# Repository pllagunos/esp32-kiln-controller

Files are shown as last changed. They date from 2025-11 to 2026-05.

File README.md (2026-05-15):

# ESP32 Electric Kiln Controller

Open-source, DIY controller for electric kilns. Built with an ESP32 microcontroller as brains to provide PID temperature control, a TFT display as an HMI, a web interface for creating and managing firing schedules and real-time data logging capability with InfluxDB and visualization in Grafana.

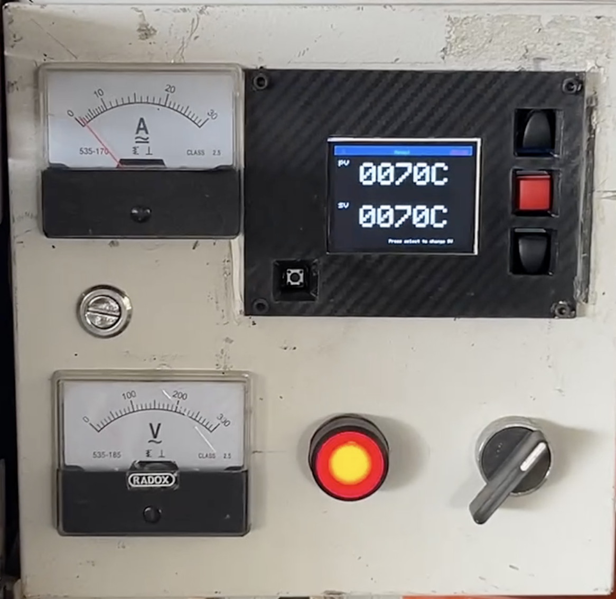
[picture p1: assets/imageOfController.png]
Kiln Controller Demo
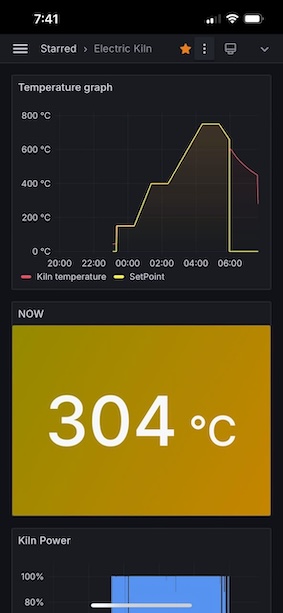
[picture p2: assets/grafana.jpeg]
Grafana
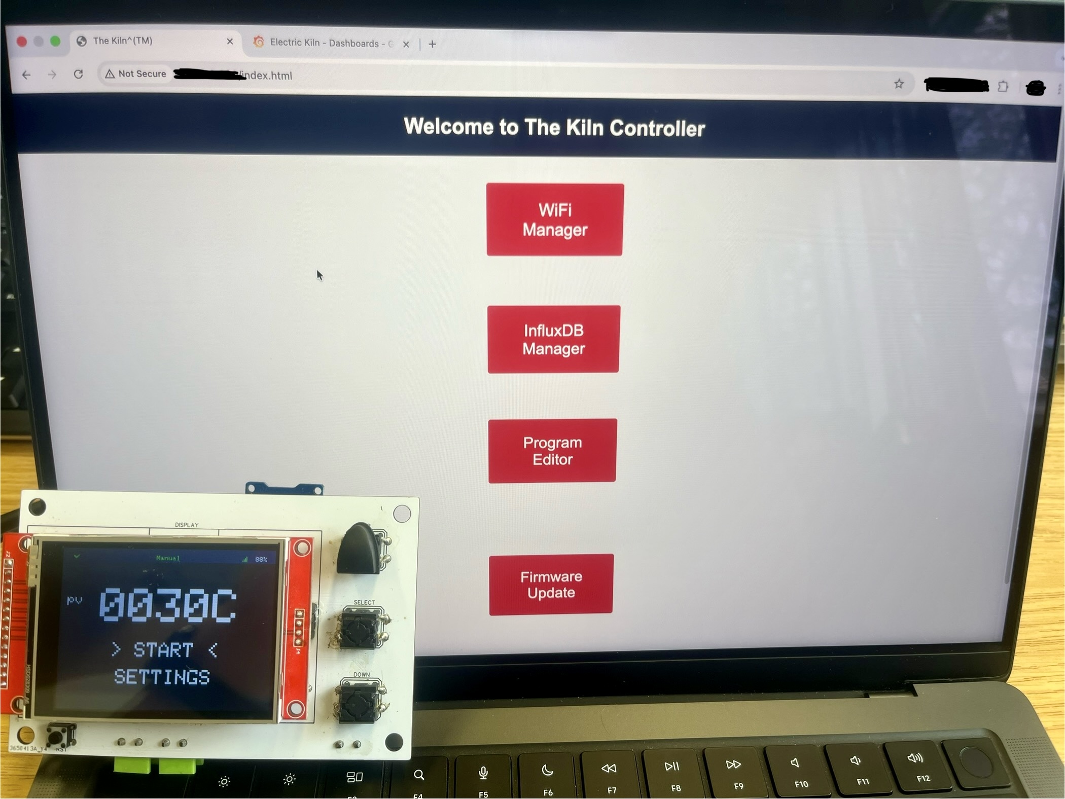
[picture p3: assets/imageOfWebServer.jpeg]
Configuration web server
|  |  |  |
|:---:|:---:|:---:|
| **Control Panel** <br> *(During manual operation with fixed SP)*  | **Grafana** <br> *(Real-time visualization of kiln)* | **Configuration Portal** <br> *(Web server for main settings)* |

## Features

* **PID Temperature Control:** Accurate and stable temperature regulation for your kiln.
* **Multi-segment Firing Programs:** Create complex firing schedules with up to 20 segments, each with a target temperature, firing rate, and hold time.
* **Captive Portal Web Interface:** Configure WiFi, InfluxDB credentials, and firing programs through a web interface hosted directly on the ESP32 — no app required. Accessible at `http://192.168.4.1` when in AP mode.
* **InfluxDB Configuration via Web UI:** Enter and update your InfluxDB credentials (URL, API token, org, bucket, timezone) through the web interface. Credentials are saved to SPIFFS and survive reboots — no recompile needed.
* **Real-time Data Logging:** Pushes temperature data to InfluxDB for live monitoring and analysis in Grafana.
* **Safety Features:** Includes a door-mounted limit switch to shut down the kiln if the door is opened.
* **Simulation Mode:** Test firing programs without actually heating the kiln.
* **OTA Firmware Updates (untested):** Check for and install firmware updates directly from the web interface. Updates are pulled from GitHub Releases automatically when a new release is published.

## Hardware

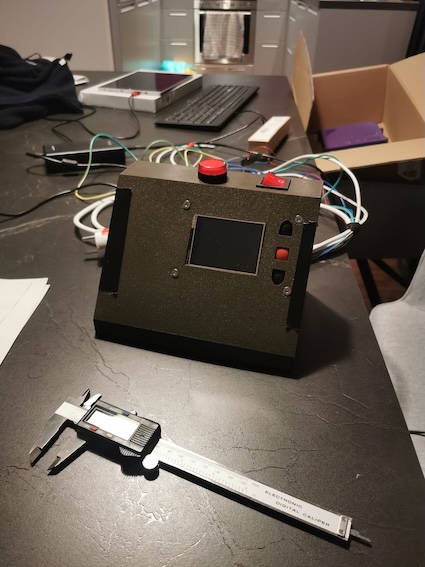
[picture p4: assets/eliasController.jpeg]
Elias controller
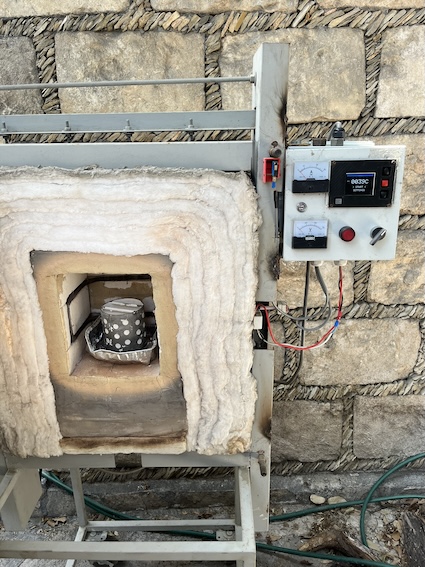
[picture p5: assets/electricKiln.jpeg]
fullKiln
|  | |
|:---:|:---:|

See the Hardware [README](hardware/README.md) for details on how to setup the electrical connections and PCBs.

## Software and Installation

This project is built using [PlatformIO](https://platformio.org/).

### Prerequisites

* [Visual Studio Code](https://code.visualstudio.com/)
* [PlatformIO IDE Extension](https://platformio.org/platformio-ide)

### Dependencies

The following libraries are used in this project and will be installed automatically by PlatformIO:

* `bodmer/TFT_eSPI @^2.5.43`
* `wollewald/ADS1220_WE @ 1.0.15`
* `br3ttb/PID @ 1.2.1`
* `tobiasschuerg/ESP8266 Influxdb @ 3.13.1`
* `me-no-dev/AsyncTCP @ 1.1.1`
* `me-no-dev/ESPAsyncWebServer @ 1.2.4`
* `bblanchon/ArduinoJson @ 6.21.4`

### Simulation mode 

The controller has the capability to use First Order Plus Dead Time (FOPDT) model, see [sensor_task](lib/task/sensor_task.cpp) :: void readSimulatedTemp() for implemenation details.

At the moment one activates/deactivates via the following line in the [user setup](/src/userSetup.h):

```cpp
const bool SIMULATION = false;   
```
(future feature: toggle simulation mode via TFT screen or web config portal)

### Installation Steps

1. **Clone the repository:**
   ```bash
   git clone https://github.com/pllagunos/ElectricKiln.git
   cd ElectricKiln
   ```

2. **Upload the filesystem:**
   * The web interface files are stored in the `/data` directory.
   * In PlatformIO, run the **"Upload Filesystem Image"** task. This uploads the HTML, CSS, and JavaScript files to the ESP32's SPIFFS partition.
   > **This step is required before first use.** The device cannot serve the web UI without it.

3. **Build and Upload:**
   * Connect your ESP32 to your computer.
   * In PlatformIO, click the **"Upload"** button (or run `pio run --target upload`).

## Configuration and Usage

The TFT display acts as the user interface together with the three push buttons next to it (Up, Select and Down).

The screen always shows a topbar with:
- Left corner: InfluxDB status: green checkmark = OK, red cross = FAIL.
- Center: Operating mode: Manual, Automatic.
- Right: Network status: OFFLINE, Connecting..., Signal Strength.

The main screen shows present temperature (PV), START and SETTINGS. The `> <` arrows shows which option is selected, to enter it one must click select.

**START SCREEN** shows preview of the program to load (or goes directly to running screen if in manual mode):

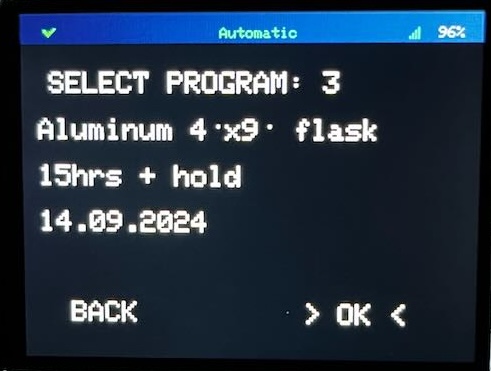
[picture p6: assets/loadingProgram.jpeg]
programsLoading


**RUN SCREEN** shows PV and SP

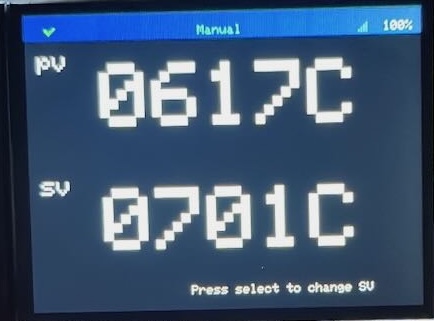
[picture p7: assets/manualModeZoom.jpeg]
manualRun

   - **Manual mode**: exit by clicking the UP button. Adjust setpoint by clicking select.
   - **Automatic mode**: exit by clicking the UP button while in the PV, SP screen. Navigate to tools screens with DOWN button.

**SETTINGS SCREEN** change firing mode, select program or enter config mode via captive portal.

### First Boot — WiFi Setup

By default the controller starts without AP mode and tries to connect to available networks. If it finds none, the controller will show an OFFLINE status in the top right corner.

To configure the WiFi network or add a new one:

1. Using the TFT display and navigation buttons go to: SETTINGS → CONFIG → START CAPTIVE PORTAL. The controller will start **Access Point (AP) mode**.
2. Connect your phone or computer to the WiFi network named **"The Kiln Controller"**.
3. A captive portal opens automatically. If it doesn't, navigate to `http://192.168.4.1`. 
4. Click **"WiFi Manager"** → scan for and select your home/studio network → enter the password → Submit.
5. When you are done configuring internal settings via the captive portal, click Exit at the bottom or > STOP CAPTIVE PORTAL < at the display.

### Creating Firing Programs

1. Open the captive portal or navigate to the device IP on your local network.
2. Click **"Program Editor"** to create and save firing programs.
3. Each segment defines a **target temperature**, **firing rate (°C/hr)**, and **hold time (min)**.

### InfluxDB Setup (Optional — for data logging)

InfluxDB credentials are configured entirely at runtime through the web UI — no recompile needed.

1. Open the captive portal (AP mode) or navigate to the device's IP address on your local network.
2. Click **"InfluxDB Manager"**.
3. Fill in:
   * **URL** — your InfluxDB instance, e.g. `https://us-east-1-1.aws.cloud2.influxdata.com`
   * **Token** — an API token with write access to your bucket
   * **Org** — your InfluxDB organization name or email
   * **Bucket** — the bucket to write data to
   * **Timezone** — POSIX tz string, e.g. `CST+6CDT,M4.1.0/2,M10.5.0/2`
4. Click **Save**. Credentials are stored in SPIFFS and survive reboots.

> **Note:** The API token is never sent back to the browser after saving — only the URL, org, bucket, and timezone are pre-filled when you revisit the form.

To set up InfluxDB Cloud and Grafana for visualization:
1. Sign up at [influxdata.com](https://www.influxdata.com/) and create a bucket.
2. Generate an API token with write access.
3. In Grafana, add InfluxDB as a data source and import the sample dashboard from `/grafana/dashboard.json`.

 **After importing the dashboard**, you'll need to update two things to match your setup:
 - **Datasource**: In each panel's query editor, switch the datasource to your own InfluxDB datasource.
 - **Bucket name**: The queries reference a bucket named `"Station of Analysis"` — update them to match whatever you named yours.
 - **Measurement name**: If you change the default data point name `"HORNO ELECTRICO"` (`/lib/task/database_task.cpp`) make sure to change this in the grafana data selector.

### Over the air (OTA) Firmware Updates

The device can check for and install firmware updates directly from GitHub Releases — no USB cable needed after initial flashing.

**How it works:**
* When a new GitHub Release is published, the CI pipeline automatically builds the firmware and filesystem image, attaches binaries to the release, and appends the firmware's MD5 hash to the release notes.
* The device compares the current `OTA_VERSION` build flag against the release **tag**.
* If a newer version is available, the "Update Now" button appears.
* Firmware integrity is verified with an MD5 hash fetched from the GitHub API before flashing.

**To check for updates:**
1. Make sure the device is connected to WiFi.
2. Navigate to the device's IP address on your local network → **"Firmware Update"** → **"Check for Update"**. 
3. If an update is found, click **"Update Now"**. The device downloads, verifies, flashes, and restarts automatically (~60 seconds).
> **Do not power off the device during an update.**

**To publish a new release (for developers):**
1. Go to the GitHub repo → Releases → "Draft a new release".
2. Create a tag (e.g. `v1.0.1`). The controller compares against the tag.
3. Click "Publish release". GitHub Actions will build and attach the firmware binary, and append the MD5 hash to the release notes automatically.

## Contributing

Contributions are welcome! Feel free to open an issue or submit a pull request.

## To Do
- [ ] MAX31855 capability (max31856 shortage)
- [ ] Autotune PID (look for existing pid autotune projects)

## License

This repository uses a dual-license model:

- Firmware and software source code are licensed under the **MIT License**. See [`LICENSE`](LICENSE).
- Hardware design files in [`hardware/`](hardware/) are licensed under the **CERN Open Hardware Licence Version 2 - Weakly Reciprocal**. See [`LICENSE-HARDWARE`](LICENSE-HARDWARE).

Unless otherwise noted, documentation and images in this repository are provided under the same license as the part of the project they accompany.

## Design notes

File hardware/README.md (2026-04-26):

# Hardware Instructions

The controller is intended for electrical kilns which use resistive heating. Power is controlled via a solid state relay (SSR) energizing the heating coil for a percentage of a heating-cycle. Through the use of a DPDT relay we have a redundant safety power disconnect when the kiln door is opened.

Using the latest PCB and a two phase 220VAC system, a hardware connection of the controller to the kiln looks like this:
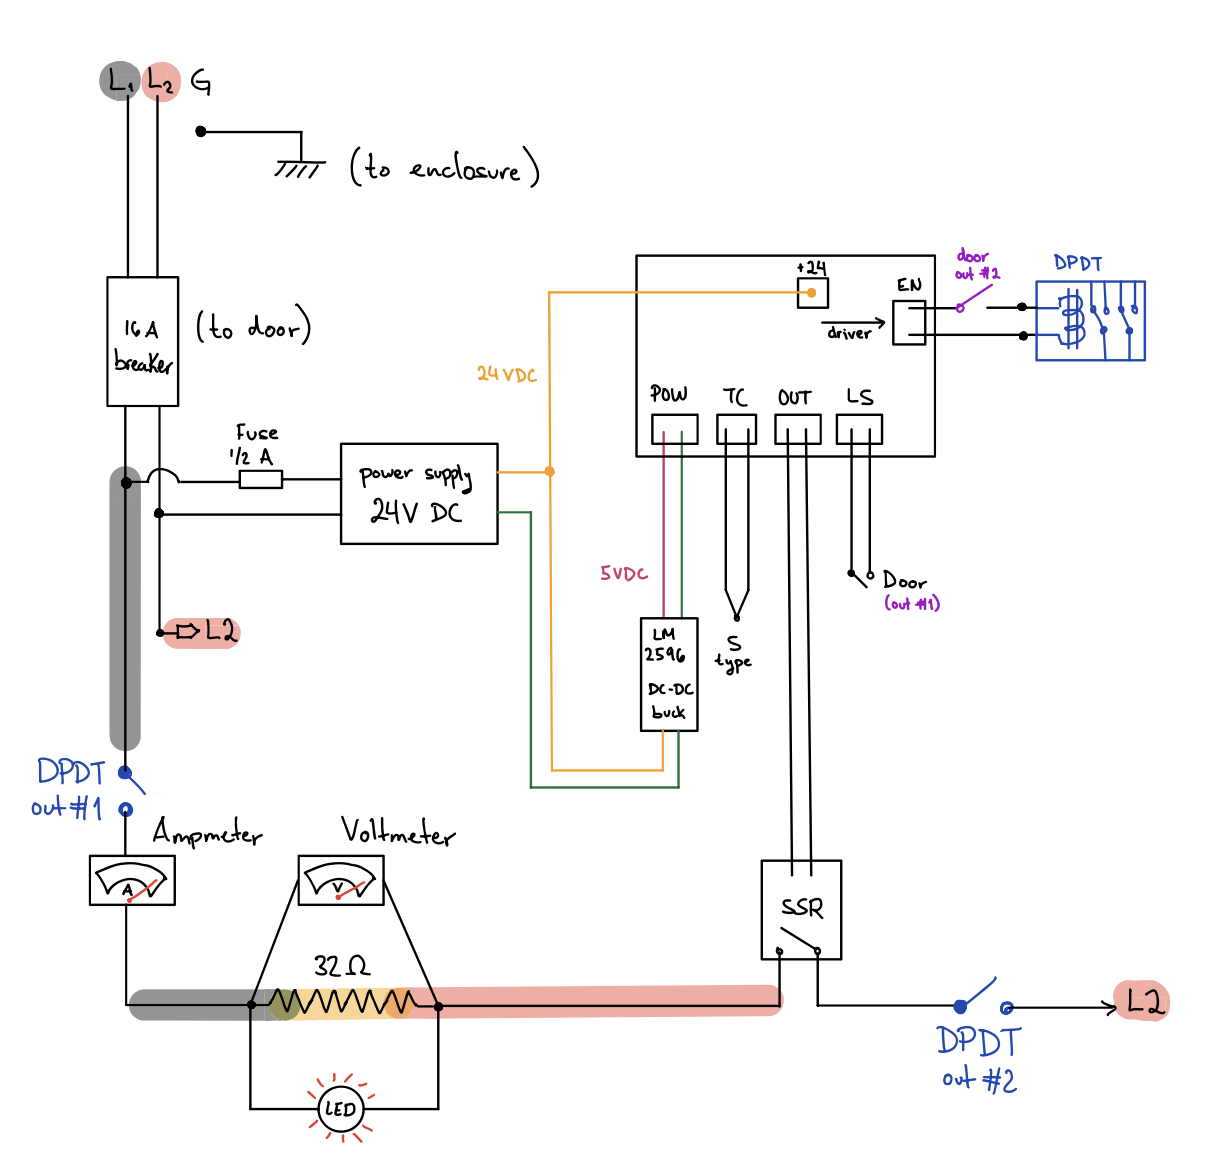
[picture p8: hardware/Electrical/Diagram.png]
Electrical Schematic
 

The electrical schematic can be adapter to one's system easily. However for safety related reasons one should always include: overcurrent protection, relay + SSR, door switch.
> **WARNING**: Wiring high voltage AC systems is a dangerous procedure if one is not familiar with mains power and safe practices. Always work with deenergized, disconnected systems. Use appropriate fuses/breakers and wires following local norms. The user is solely responsible for any damage or injury that may happen from inappropriate implementations.

## License

The hardware design files in this directory are licensed under the **CERN Open Hardware Licence Version 2 - Weakly Reciprocal**. See [`../LICENSE-HARDWARE`](../LICENSE-HARDWARE) for the full license text.

## Hardware Components

### Electronics

* **Microcontroller:** ESP32-DOIT-DEVKIT-V1 board
* **Thermocouple Amplifier:** MAX31856 thermocouple module board or an ADS1220 ADC converter.
* **Thermocouple:** Type-S Thermocouple (but configurable for B, K, R, N, E, J, and T types).
* **Solid State Relay (SSR):** To control the heating elements.
* **Main DPDT Relay:** Double pole double throw, disconnects main power.
* **TFT Display:** ILI9341 320x240 SPI display for the user interface (2.4 or 2.8 inch).
* **Buttons:** Three push buttons for on-device navigation (Up, Select, Down).
* **Limit Switch:** A safety switch for the kiln door.
* **Reset Button:** A reset button for the ESP32.

### PCB and Wiring

The PCB design files can be found in the `/hardware/PCB` directory. 

- `ADS1220 versions` is the current software supported version. The problem with this version is its missing some key details and I haven't done routing / manufacturing. The ESP32 pinout file is at [PINOUT.xlsx](PCB/ADS1220%20versions/PINOUT_HornoElectrico.xlsx).

- `MAX31856 versions` are older PCBs I designed when the project utilized a MAX31856 and an SD card. The ESP32 pinout file is at [PINOUT.xlsx](PCB/MAX31856%20versions/PINOUT_EliasKiln.xlsx). 

Currently I am using the MAX31856 version PCB with modifications that make it reassemble the ADS1220 PCB: 
* The MAX31856 SPI pins were rerouted to a small perfboard where I placed the ADS1220 in place. 
* The SD card module is not needed and I modified it to use the kiln DPDT with a relay driver as follows:

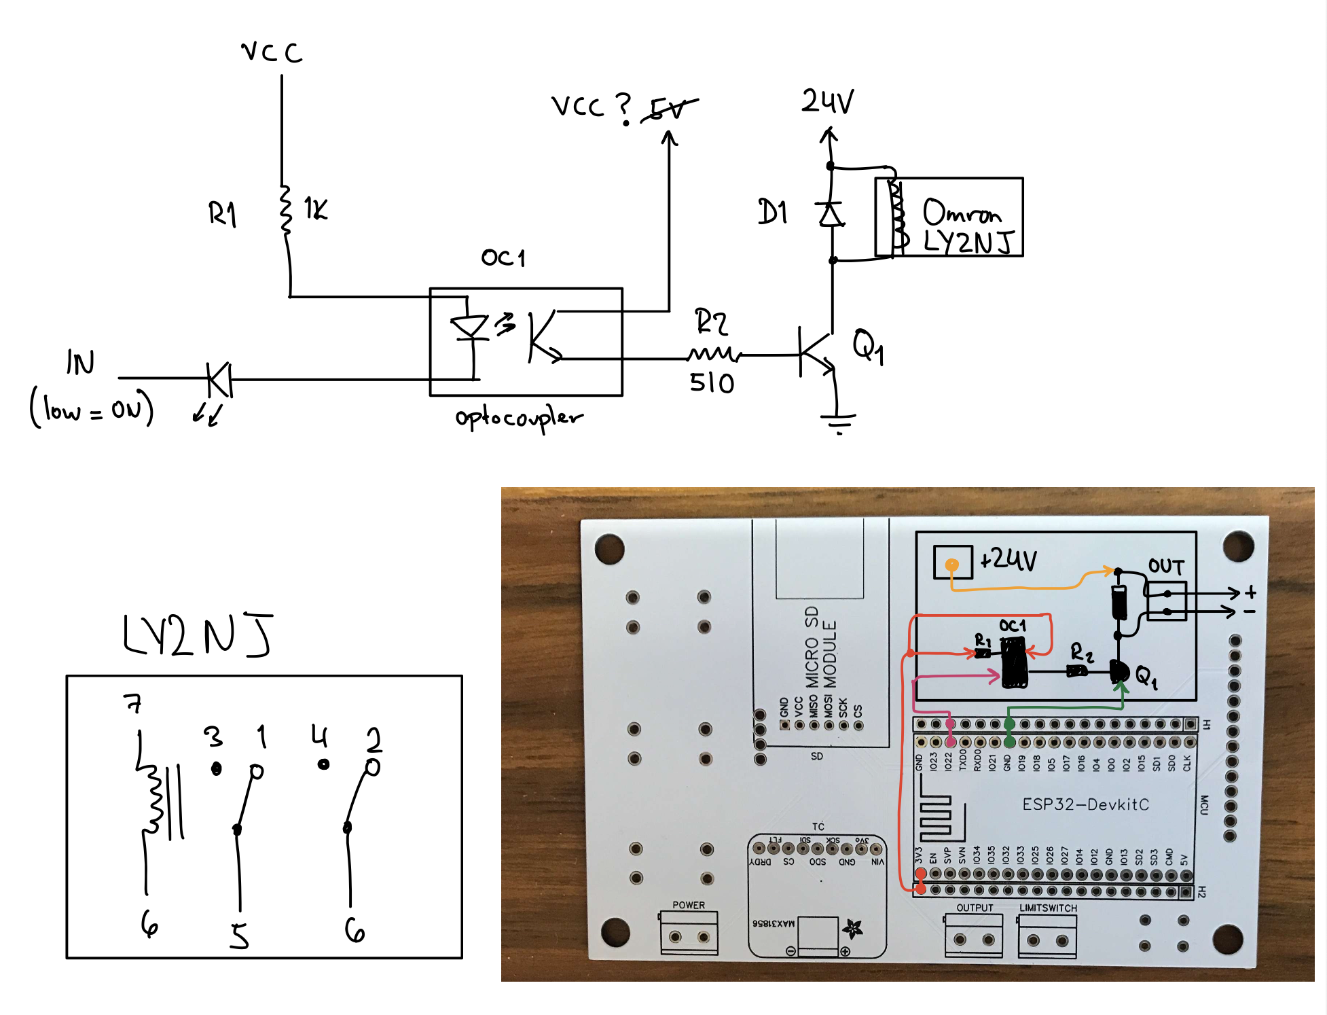
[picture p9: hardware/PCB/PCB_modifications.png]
modifications


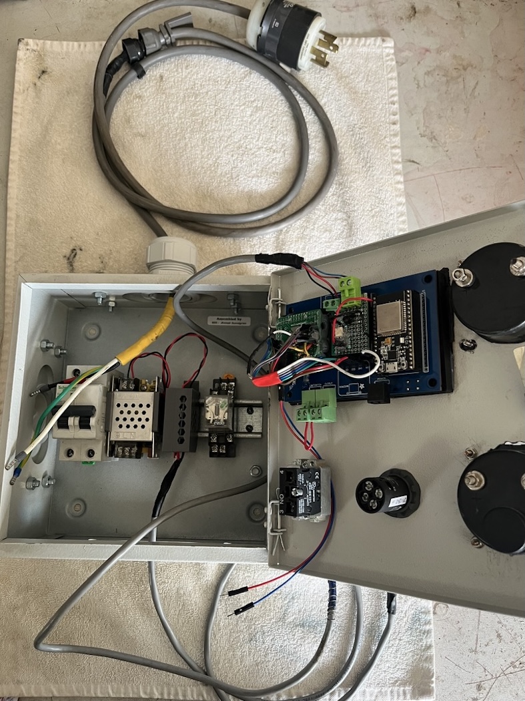
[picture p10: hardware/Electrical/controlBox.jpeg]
controlBox


Since these modifications are custom and would be a lot of work for anybody, there are currently only two approaches to using this project:

1. Finish the ADS1220 PCB design and fabricate it, testing it works as expected.
2. Use the MAX31856 PCB design. Software needs added compatibility of MAX31856 library (easy). Hardware will need a hack to use the safety relay (easy, use any pin to drive relay board directly).

### Optional ADS1220 thermocouple amplifier
The ADS1220 thermocouple software and electronics design are based on the following article: [TI Precision Deisgns: Precision Thermocouple Measurement with the ADS1118](https://www.ti.com/lit/ug/slau509/slau509.pdf?ts=1700893585527&ref_url=https%253A%252F%252Fwww.google.com%252F)

The article is very informative and definetely worth a read to better understand how the Electric Kiln Controller reads temperatures using the ADS1220 ADC. 

For generating the necessary lookup tables I created a [python notebook](./TC%20table%20optimization/ThermocoupleCSV.ipynb) which uses the NIST ITS-90 Thermocouple Database. The generated lookup tables csv files are then uploaded to the `data/` folder which is then uploaded to ESP32's flash. The notebook is quite self explanatory, includes a testing section for validation and can be extended to generate more than the available (K, R, S) thermocouple tables by simply loading the respective NIST table.

### New PCB to-do list:

- [ ] Include 5V stepdown in board
- [ ] Do routing 
- [ ] Create gerber files
- [ ] Potentially use 24V system with chineseium PCB powersupplies

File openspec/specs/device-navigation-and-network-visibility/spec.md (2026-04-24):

## ADDED Requirements

### Requirement: Secondary web UI pages provide explicit navigation controls
The system SHALL provide Back and Home navigation controls on secondary web UI pages so operators can return to the main dashboard or the previous relevant UI flow without relying on browser chrome.

#### Scenario: User navigates from a secondary page to the dashboard
- **WHEN** the user is on a secondary web UI page and activates Home
- **THEN** the UI returns the user to the main dashboard

#### Scenario: User navigates back from a secondary page
- **WHEN** the user is on a secondary web UI page and activates Back
- **THEN** the UI returns the user to the previous relevant page or flow

### Requirement: CONFIG TFT screen shows the active IP address
The system SHALL display the active device IP address on the CONFIG TFT subscreen so operators can discover how to reach the device from the controller itself.

#### Scenario: Device is connected in station mode
- **WHEN** the device has an active station-mode network connection
- **THEN** the CONFIG TFT subscreen displays the current station IP address

#### Scenario: Captive portal is active
- **WHEN** the captive portal is active
- **THEN** the CONFIG TFT subscreen displays the active AP IP address

#### Scenario: No IP address is available
- **WHEN** the device does not have an active IP address for the current mode
- **THEN** the CONFIG TFT subscreen shows that the IP address is unavailable

### Requirement: CONFIG TFT screen allows thermocouple-type selection
The system SHALL provide a `Change TC Type` option on the TFT CONFIG subscreen and SHALL allow the operator to open a dedicated thermocouple-type selection subscreen from that option.

#### Scenario: Operator opens thermocouple-type selection
- **WHEN** the operator highlights `Change TC Type` on the CONFIG TFT subscreen and presses select
- **THEN** the UI opens a dedicated thermocouple-type selection subscreen

### Requirement: Thermocouple-type selection uses the standard TFT button flow
The thermocouple-type selection subscreen SHALL use the existing up/down/select button interaction pattern to browse available thermocouple types and confirm the selected value.

#### Scenario: Operator browses thermocouple types
- **WHEN** the operator is on the thermocouple-type selection subscreen and presses the up or down buttons
- **THEN** the UI cycles through the available thermocouple-type options one step at a time

#### Scenario: Operator confirms the highlighted thermocouple type
- **WHEN** the operator presses select on the thermocouple-type selection subscreen
- **THEN** the highlighted thermocouple type becomes the selected runtime thermocouple type
- **AND** the UI returns to the appropriate parent CONFIG flow or otherwise indicates the selection was accepted

### Requirement: Active thermocouple-type changes are highlighted in orange
The thermocouple-type value displayed while the operator is actively toggling through options SHALL render in orange on the TFT.

#### Scenario: Operator is actively changing the thermocouple type
- **WHEN** the operator is browsing thermocouple-type values before confirmation
- **THEN** the currently highlighted thermocouple-type text is shown in orange

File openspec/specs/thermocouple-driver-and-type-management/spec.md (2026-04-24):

### Requirement: The firmware supports build-time thermocouple driver selection
The system SHALL allow the firmware build to target either the ADS1220 thermocouple path or the MAX31856 thermocouple path from `userSetup.h`, and the configured thermocouple driver SHALL be the only thermocouple hardware path initialized at runtime.

#### Scenario: Firmware is built for ADS1220
- **WHEN** the build is configured to use ADS1220 as the thermocouple driver
- **THEN** the sensor task initializes and reads temperature through the ADS1220 path
- **AND** the MAX31856 hardware path is not initialized

#### Scenario: Firmware is built for MAX31856
- **WHEN** the build is configured to use MAX31856 as the thermocouple driver
- **THEN** the sensor task initializes and reads temperature through the MAX31856 path
- **AND** the ADS1220 hardware path is not initialized

### Requirement: Thermocouple type is runtime-configurable and persisted
The system SHALL maintain a runtime thermocouple-type setting that is initialized from the configured default when no persisted value exists, SHALL persist operator changes, and SHALL reuse the persisted value after restart.

#### Scenario: Device boots without a stored thermocouple type
- **WHEN** the firmware starts and no thermocouple type has been stored previously
- **THEN** the runtime thermocouple type is seeded from the configured default in `userSetup.h`

#### Scenario: Operator changes thermocouple type
- **WHEN** the operator selects and confirms a new thermocouple type from the TFT flow
- **THEN** the system stores the selected thermocouple type for future boots
- **AND** the new thermocouple type becomes the runtime thermocouple type

#### Scenario: Device restarts after a thermocouple type change
- **WHEN** the firmware starts after a thermocouple type has been stored
- **THEN** the runtime thermocouple type uses the stored value instead of reverting to the compile-time default

### Requirement: The active driver applies runtime thermocouple-type changes
The system SHALL apply the current runtime thermocouple type through the configured driver both during initialization and after a confirmed runtime change.

#### Scenario: MAX31856 applies the selected type
- **WHEN** MAX31856 is the configured driver and the runtime thermocouple type is available
- **THEN** the system configures MAX31856 to use the selected thermocouple type before or during temperature acquisition

#### Scenario: ADS1220 applies the selected type
- **WHEN** ADS1220 is the configured driver and the runtime thermocouple type is available
- **THEN** the system loads and uses the lookup-table data required for the selected thermocouple type before temperature acquisition continues

#### Scenario: Runtime type changes after boot
- **WHEN** the operator confirms a different thermocouple type while the device is running
- **THEN** the sensor task reapplies the thermocouple-type configuration for the active driver
- **AND** subsequent temperature reads use the newly selected type

### Requirement: Unsupported thermocouple-type or driver errors are surfaced clearly
The system SHALL not silently coerce an unsupported thermocouple type to another type, and SHALL provide clear fault or initialization feedback when the configured driver cannot initialize or cannot apply the selected thermocouple type.

#### Scenario: Driver initialization fails
- **WHEN** the configured thermocouple driver cannot be initialized
- **THEN** the system surfaces a clear thermocouple-related error to the operator

#### Scenario: ADS1220 lacks data for the selected type
- **WHEN** ADS1220 is configured and the selected thermocouple type does not have usable lookup-table data
- **THEN** the system reports that the selected thermocouple type cannot be applied
- **AND** the thermocouple path is not treated as successfully initialized

#### Scenario: Operator selects a type that cannot be applied
- **WHEN** the operator confirms a thermocouple type that the configured driver cannot use
- **THEN** the system preserves the selected thermocouple type value
- **AND** the system exposes a fault or error state instead of silently substituting another type

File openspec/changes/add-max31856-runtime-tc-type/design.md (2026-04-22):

## Context

The current firmware hard-codes a single thermocouple driver path in `sensor_task.cpp`: ADS1220 setup, ADS1220 reads, and ADS1220 lookup-table loading driven by the compile-time `TCTYPE` string in `userSetup.h`. The TFT already has a CONFIG submenu and already persists operator-selected values with `Preferences`, but thermocouple type is not part of that runtime configuration flow.

This change needs to add a second supported driver (MAX31856), preserve the simple compile-time hardware choice in `userSetup.h`, and introduce a runtime thermocouple-type selection flow that works across both supported drivers. The TFT interaction model must stay consistent with the current up/down/select navigation pattern and the existing orange highlight behavior used for actively adjusted values.

Constraints:
- The project is embedded and resource-constrained; the design should extend the existing sensor task and TFT state machine rather than add a large new abstraction layer.
- ADS1220 and MAX31856 support different thermocouple-type application mechanisms: ADS1220 uses SPIFFS CSV lookup tables, while MAX31856 uses hardware enums/register configuration.
- The current system already has known single-user assumptions in the local UI/task model, so the runtime TC-type flow should stay within that model instead of introducing multi-user configuration paths.

## Goals / Non-Goals

**Goals:**
- Allow the firmware to be compiled for either ADS1220 or MAX31856 hardware from `userSetup.h`.
- Provide one runtime thermocouple-type setting that is persisted and applied by whichever configured driver is active.
- Add a TFT CONFIG entry and a dedicated TC-type selection subscreen with up/down/select controls.
- Keep the UI behavior consistent with the existing TFT screens, including orange text while the value is being changed.
- Preserve clear initialization or fault feedback when the selected thermocouple driver or thermocouple type cannot be applied.

**Non-Goals:**
- Adding web-based thermocouple-driver or thermocouple-type configuration.
- Supporting simultaneous dual-driver operation in one firmware image.
- Reworking the full TFT navigation architecture beyond the new CONFIG branch and selection subscreen.
- Solving unrelated display refresh bugs from the reference document unless directly required by the new flow.

## Decisions

### 1. Use compile-time driver selection in `userSetup.h`
The firmware will expose mutually exclusive compile-time driver-selection macros/constants in `userSetup.h` so the build is explicitly targeted to either ADS1220 or MAX31856 hardware.

**Why:** This matches the current project style, keeps the runtime model simple, and avoids dragging unused driver code and hardware initialization into a single dynamically switched image.

**Alternatives considered:**
- **Runtime driver selection:** rejected because the hardware is fixed per device and the added branching, detection logic, and failure modes do not buy much value.
- **Separate forks/files per driver:** rejected because it would duplicate most of the sensor-task flow and drift over time.

### 2. Introduce one shared runtime thermocouple-type state
The runtime-selected thermocouple type will live in shared state (seeded from `userSetup.h` defaults, persisted through `Preferences`, and read by both the GUI and sensor task).

**Why:** The UI needs to display and update the value, while the sensor task needs to apply it to the active driver. Shared state also lets the system reuse the current task-semaphore approach already used for temperatures and faults.

**Alternatives considered:**
- **Leave `TCTYPE` as compile-time-only:** rejected because it does not satisfy runtime reconfiguration.
- **Store the type only inside `Preferences`:** rejected because the sensor task and GUI need a synchronized in-memory value during operation.

### 3. Apply thermocouple-type changes inside the sensor task
The sensor task remains the owner of thermocouple hardware state. It will initialize the active driver at boot, detect runtime TC-type changes, and apply the new type using driver-specific logic:
- MAX31856: map the selected char to `max31856_thermocoupletype_t` and call the hardware setter.
- ADS1220: reload the corresponding lookup table for the selected type and update readiness/fault state if the type is unsupported or the table cannot be loaded.

**Why:** This keeps hardware mutations in one place and avoids letting the UI task manipulate sensor drivers directly.

**Alternatives considered:**
- **Apply type changes directly from the GUI:** rejected because it crosses task boundaries and couples TFT interaction to SPI/SPIFFS operations.
- **Create a new dedicated thermocouple manager task:** rejected as too much complexity for one sensor path.

### 4. Separate “selection in progress” UI state from “applied” driver state
The GUI will track the currently highlighted thermocouple type while the operator is browsing options, and it will only persist/commit when select is pressed. The highlighted text will render in orange while this browsing state is active.

**Why:** This matches the existing manual-temperature-adjustment pattern in `gui.cpp`, where orange indicates an actively changing value.

**Alternatives considered:**
- **Apply on every up/down press:** rejected because it causes repeated hardware churn and noisier error paths while browsing.
- **Use white text only:** rejected because the request explicitly calls for orange while toggling and the project already uses orange for active edits.

### 5. Persist the public TC type independently from driver-specific implementation details
The persisted value will remain a canonical single-character thermocouple-type code (`B`, `E`, `J`, `K`, `N`, `R`, `S`, `T`). Unsupported combinations will be surfaced as initialization/runtime errors instead of silently remapping to another type.

**Why:** The UI and preferences should reflect what the operator selected, not an implementation-specific fallback. This also keeps behavior explicit if ADS1220 only supports a subset of types via lookup tables.

**Alternatives considered:**
- **Silently coerce unsupported values to `K` or the build default:** rejected because it hides operator intent and makes hardware behavior ambiguous.

## Risks / Trade-offs

- **Unsupported TC type for ADS1220 lookup tables** → The UI may allow a selection that the current ADS1220 data files do not support. Mitigation: specify explicit fault/error behavior and mark the driver unready until a supported type is selected.
- **MAX31856 library integration differences** → The Adafruit API and fault semantics may differ from the reference code. Mitigation: keep the spec at behavioral level and call out the mapping/setup work explicitly in tasks.
- **UI-state growth in `gui.cpp`** → Adding another CONFIG subscreen increases the existing string-based screen-state logic. Mitigation: reuse the established `screen == "..."; selection index; readButtons()` pattern instead of inventing a second navigation model.
- **Persistence mismatch on first boot after upgrade** → Existing devices only have compile-time `TCTYPE`. Mitigation: seed preferences from the compile-time default if no runtime value has been stored yet.
- **More initialization/fault paths** → Two drivers plus runtime type changes create more ways to fail. Mitigation: keep the sensor task as the single owner of readiness/error state and specify clear operator-visible error behavior.

## Migration Plan

1. Add compile-time thermocouple-driver selection and runtime TC-type shared state/defaulting.
2. Extend the sensor task with MAX31856 support and driver-specific TC-type application.
3. Add persistence for the runtime TC type so existing devices bootstrap from the compile-time default once and then reuse the stored value.
4. Extend the TFT CONFIG menu with `Change TC Type` and the selection subscreen.
5. Validate both driver builds and confirm the existing ADS1220 path still behaves correctly when runtime TC-type changes are not used.

Rollback is straightforward: rebuild with the previous single-driver ADS1220 path and ignore the runtime preference key. Existing stored TC-type values can be left in preferences because the older firmware does not read them.

## Open Questions

- Whether the project should constrain the TFT selection list to only the types supported by the configured driver, or expose the full thermocouple-type list and surface unsupported selections as runtime errors.
- Whether MAX31856-specific fault details should be surfaced only through the existing generic TFT error flow or also stored for richer diagnostics elsewhere.

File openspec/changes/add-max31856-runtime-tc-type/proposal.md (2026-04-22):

## Why

The controller currently assumes the ADS1220 thermocouple path at build time and a fixed thermocouple type from `userSetup.h`, which blocks MAX31856-based hardware and forces thermocouple-type changes to require a rebuild. This change adds hardware flexibility and lets operators adjust the configured thermocouple type from the device UI when their installed driver supports it.

## What Changes

- Add build-time thermocouple driver selection in `userSetup.h` so the firmware can be compiled for either ADS1220 or MAX31856 hardware.
- Add MAX31856 initialization, read, fault-handling, and thermocouple-type application alongside the existing ADS1220 path.
- Introduce a shared runtime thermocouple-type setting that can be applied after boot and persisted across restarts.
- Extend the TFT CONFIG flow with a `Change TC Type` entry and a dedicated selection subscreen that uses up/down arrows plus select confirmation.
- Render the thermocouple-type value in orange while the user is actively changing it.
- Preserve existing kiln-control behavior when the selected driver or thermocouple type is unavailable, including clear fault or initialization feedback.

## Capabilities

### New Capabilities
- `thermocouple-driver-and-type-management`: Select the thermocouple driver at build time, support MAX31856 hardware, and allow runtime thermocouple-type selection and persistence through the TFT UI.

### Modified Capabilities
- `device-navigation-and-network-visibility`: Expand the CONFIG TFT flow so operators can enter a dedicated thermocouple-type selection screen from CONFIG in addition to the existing IP-visibility behavior.

## Impact

- `src/userSetup.h` thermocouple configuration constants and driver-selection compile-time switches.
- `src/common.h` and shared runtime state for thermocouple type and initialization or fault status.
- `lib/task/sensor_task.cpp` hardware initialization, reading logic, thermocouple-type application, and error handling for both ADS1220 and MAX31856.
- `lib/gui/gui.cpp` CONFIG submenu structure, thermocouple-type selection screen, button handling, and highlight color behavior.
- Preferences or persistent settings storage used by the TFT flow to remember the selected thermocouple type across restarts.

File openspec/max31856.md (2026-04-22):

# REFERENCE CODE

User Setup:
// thermocouple driver

#define TC_DRIVER_MAX31856
// #define TC_DRIVER_ADS1220

constexpr int TC_CS_PIN        = 33; // MAX31856 / ADS1220 chip-select
constexpr int TC_DRDY_PIN      = 13; // ADS1220 data-ready (unused with MAX31856)

ReadSensors TASK:

#include <ADS1220_WE.h>
#include <Adafruit_MAX31856.h>

#ifdef TC_DRIVER_MAX31856
    // Maps the single-char thermocouple type to the Adafruit MAX31856 enum.
    max31856_thermocoupletype_t tcTypeFromChar(char t) {
        switch (t) {
            case 'B': return MAX31856_TCTYPE_B;
            case 'E': return MAX31856_TCTYPE_E;
            case 'J': return MAX31856_TCTYPE_J;
            case 'K': return MAX31856_TCTYPE_K;
            case 'N': return MAX31856_TCTYPE_N;
            case 'R': return MAX31856_TCTYPE_R;
            case 'S': return MAX31856_TCTYPE_S;
            case 'T': return MAX31856_TCTYPE_T;
            default:  return MAX31856_TCTYPE_K;
        }
    }
#endif

void setupADS1220(ADS1220_WE &ads);
void setupThermocouple(Adafruit_MAX31856 &thermocouple);
void readTemps(Adafruit_MAX31856 &thermocouple);
void readTemps(ADS1220_WE &ads);

setup part:

#if defined(TC_DRIVER_MAX31856)
        static Adafruit_MAX31856 thermocouple(TC_CS_PIN);
        if (!startupSim) setupThermocouple(thermocouple);
    #elif defined(TC_DRIVER_ADS1220)
        static ADS1220_WE ads(TC_CS_PIN, TC_DRDY_PIN);
        if (!startupSim) setupADS1220(ads);
    #endif

loop part (for(;;)): (spi mutexes are not needed!)

        // Apply TC type changes to hardware whenever the user updates g_tcType.
        // Guard on !startupSim: if the device booted in simulation mode the hardware
        // drivers were never initialised and must not be called at runtime.
        #if defined(TC_DRIVER_MAX31856)
        if (!currentSim && !startupSim && currentTcType != lastAppliedTcType) {
            xSemaphoreTake(g_spiMutex, portMAX_DELAY); 
            thermocouple.setThermocoupleType(tcTypeFromChar(currentTcType));
            xSemaphoreGive(g_spiMutex);
            lastAppliedTcType = currentTcType;
        }
        #elif defined(TC_DRIVER_ADS1220)
        if (!currentSim && !startupSim && currentTcType != lastAppliedTcType) {
            table.clear();
            // SPIFFS.begin() is idempotent when already mounted; also handles the
            // edge case where a sim-mode boot skipped the initial mount.
            if (SPIFFS.begin()) {
                if (currentTcType == 'R') readCSV("/thermocouple_table_r.csv", table);
                else if (currentTcType == 'K') readCSV("/thermocouple_table_k.csv", table);
                else if (currentTcType == 'S') readCSV("/thermocouple_table_s.csv", table);
                // Mark applied whether or not the table loaded — prevents futile
                // retries for unsupported types or permanently missing CSV files.
                // (SPIFFS failure is still retried via the else-branch below.)
                lastAppliedTcType = currentTcType;
                xSemaphoreTake(g_mutex, portMAX_DELAY);
                g_tcInitialized = !table.empty();
                if (!table.empty()) {
                    g_initErr[0] = '\0';
                } else if (g_initErr[0] == '\0') {
                    // readCSV sets g_initErr on file-not-found; if it didn't
                    // (unsupported type — no branch above), set a generic message.
                    snprintf(g_initErr, sizeof(g_initErr),
                             "TC type %c: no ADS1220 CSV table", currentTcType);
                }
                xSemaphoreGive(g_mutex);
            } else {
                // SPIFFS unavailable: leave lastAppliedTcType unchanged so the
                // same type is retried once SPIFFS recovers.
                xSemaphoreTake(g_mutex, portMAX_DELAY);
                snprintf(g_initErr, sizeof(g_initErr), "SPIFFS mount failed");
                g_tcInitialized = false;
                xSemaphoreGive(g_mutex);
            }
        }
        #endif
        // too much code to be in the loop, migrate to function with some appropriate name like handleTcType()

        // reading part

        (else?)if (!currentSim && tcReady && millis() - tempStart >= (unsigned long)tempCycle) {
            #if defined(TC_DRIVER_MAX31856)
                xSemaphoreTake(g_spiMutex, portMAX_DELAY);
                readTemps(thermocouple);
                xSemaphoreGive(g_spiMutex);
            #elif defined(TC_DRIVER_ADS1220)
                xSemaphoreTake(g_spiMutex, portMAX_DELAY);
                readTemps(ads);
                xSemaphoreGive(g_spiMutex);
            #endif
            tempStart = millis();
        }

        void readTemps(Adafruit_MAX31856 &thermocouple) {

            temp = thermocouple.readThermocoupleTemperature();
            uint8_t faultCode = thermocouple.readFault();

            xSemaphoreTake(g_mutex, portMAX_DELAY);
            g_tcFault     = (faultCode != 0);
            g_tcFaultCode = faultCode;                         // raw bitmask for host diagnostics
            if (temp < 5000.0f && temp > 0.0f) g_temperature = temp;
            xSemaphoreGive(g_mutex);
        }

        // ── Thermocouple driver setup ───────────────────────────────────────────

void setupADS1220(ADS1220_WE &ads) {
    bool ok = false;
    while (!ok) {
        xSemaphoreTake(g_spiMutex, portMAX_DELAY);
        ok = ads.init();
        if (ok) {
            ads.setCompareChannels(ADS1220_MUX_0_1);
            ads.setGain(ADS1220_GAIN_32);
        }
        xSemaphoreGive(g_spiMutex);
        if (!ok) {
            xSemaphoreTake(g_mutex, portMAX_DELAY);
            snprintf(g_initErr, sizeof(g_initErr), "ADS1220 not found");
            xSemaphoreGive(g_mutex);
            delay(200);
        }
    }

    if (!SPIFFS.begin()) {
        xSemaphoreTake(g_mutex, portMAX_DELAY);
        snprintf(g_initErr, sizeof(g_initErr), "SPIFFS mount failed");
        xSemaphoreGive(g_mutex);
    } else {
        xSemaphoreTake(g_mutex, portMAX_DELAY);
        char tcType = g_tcType;
        xSemaphoreGive(g_mutex);

        if (tcType == 'R') readCSV("/thermocouple_table_r.csv", table);
        if (tcType == 'K') readCSV("/thermocouple_table_k.csv", table);
        if (tcType == 'S') readCSV("/thermocouple_table_s.csv", table);
    }

    xSemaphoreTake(g_mutex, portMAX_DELAY);
    g_tcInitialized = !table.empty();
    if (!table.empty()) g_initErr[0] = '\0'; // table loaded — clear prior error
    xSemaphoreGive(g_mutex);
}

void setupThermocouple(Adafruit_MAX31856 &thermocouple) {
    bool ok = false;
    while (!ok) {
        xSemaphoreTake(g_spiMutex, portMAX_DELAY);
        ok = thermocouple.begin();
        xSemaphoreGive(g_spiMutex);
        if (!ok) {
            xSemaphoreTake(g_mutex, portMAX_DELAY);
            snprintf(g_initErr, sizeof(g_initErr), "MAX31856 not found");
            xSemaphoreGive(g_mutex);
            delay(200);
        }
    }

    xSemaphoreTake(g_mutex, portMAX_DELAY);
    char tcType = g_tcType;
    g_initErr[0] = '\0'; // hardware found — clear any prior not-found error
    xSemaphoreGive(g_mutex);

    xSemaphoreTake(g_spiMutex, portMAX_DELAY);
    thermocouple.setThermocoupleType(tcTypeFromChar(tcType));
    thermocouple.setConversionMode(MAX31856_CONTINUOUS);
    xSemaphoreGive(g_spiMutex);

    xSemaphoreTake(g_mutex, portMAX_DELAY);
    g_tcInitialized = true;
    xSemaphoreGive(g_mutex);
}

// MAX31856 error strings (from a different project)
case regAddress::TC_ERROR_CODE :
      tcErrorType = "";
      if (value & MAX31856_FAULT_CJRANGE) tcErrorType += "CJ RANGE\n";
      if (value & MAX31856_FAULT_TCRANGE) tcErrorType += "TCRANGE\n";
      if (value & MAX31856_FAULT_CJHIGH)  tcErrorType += "CJ HIGH\n";
      if (value & MAX31856_FAULT_CJLOW)   tcErrorType += "CJ LOW\n";
      if (value & MAX31856_FAULT_TCHIGH)  tcErrorType += "TC HIGH\n";
      if (value & MAX31856_FAULT_TCLOW)   tcErrorType += "TC LOW\n";
      if (value & MAX31856_FAULT_OVUV)    tcErrorType += "Over/Under Voltage\n";
      if (value & MAX31856_FAULT_OPEN)    tcErrorType += "TC OPEN\n";

      break;

// Call to display error message on TFT display
disp_error_msg("TC ERROR", tcErrorType, "Restart Kiln Controller");

//  DISPLAYERRORMESSAGE: PRINT AN ERROR ON TFT
void disp_error_msg(String title, String message1, String message2) {
  // xSemaphoreTake(disp_mutex, portMAX_DELAY);  // take semaphore
  tft.fillScreen(TFT_BLACK);
  tft.setTextColor(TFT_RED, TFT_BLACK);
  tft.setTextSize(4);
  tftPrintCenterWidth("ERROR", 50);
  tft.setTextColor(TFT_WHITE, TFT_BLACK);
  tft.setTextSize(2);
  tftPrintCenterWidth(title, 100);
  tftPrintCenterWidth(message1, 130);
  tftPrintCenterWidth(message2, 210);
  // xSemaphoreGive(disp_mutex);
}

## Current bug
When no thermocouple driver is detected upon init, the display should show a clear error of this. However the way the TFT is rendering the error, it's flashing very often together with the START screen, making it look defective.

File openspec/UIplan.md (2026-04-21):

**Implementation Plan**

The goal is to upgrade the ESP32 kiln controller’s firing program workflow from a single manual-entry form into a lightweight program library plus editor, while keeping the implementation simple enough for plain HTML, CSS, JS, and filesystem-backed firmware handlers.

1. Discovery and compatibility
   - Locate the current firing program HTML, JS, CSS, and the firmware handler that writes JSON into SPIFFS or LittleFS.
   - Confirm the current program JSON schema, storage directory, filename pattern, and any existing endpoints used by the page.
   - Identify whether existing saved files contain legacy fields such as program_number and whether those files must remain readable.

2. Data model cleanup
   - Standardize new and edited programs to this schema: name, created_date, duration, segments.
   - Standardize each segment to: target_temperature, firing_rate, holding_time.
   - Remove program_number from the UI and from newly saved JSON.
   - Keep legacy compatibility by ignoring program_number if present in old files and removing it when an old file is re-saved.

3. Program storage and naming
   - Replace manual program numbering with automatic filename generation.
   - Generate a slug from program name and created_date.
   - Ensure filenames are filesystem-safe and collision-safe by adding a numeric suffix when necessary.
   - Support editing existing programs so that if name or created_date changes, the backing filename can be updated cleanly.

4. Firmware API additions
   - Add a list endpoint that returns saved program metadata.
   - Add a get endpoint that returns one full program by id or slug.
   - Add a create or update endpoint that saves a program and returns its final id.
   - Optionally add a delete endpoint if straightforward.
   - Make the save handler validate payload shape and compute or verify duration before writing.

5. Frontend structure
   - Split the current single page into two simple views:
   - A program library page listing saved programs with actions for New and Edit.
   - A program editor page for creating and editing programs.
   - Keep the implementation framework-free and lightweight.

6. Editor behavior
   - The editor should expose only name, created date, and segment rows.
   - Each segment row should include target temperature, firing rate, and hold time.
   - Users should be able to add and remove segments dynamically in the browser before saving.
   - The editor should support create mode and edit mode using a query parameter or route segment.

7. Automatic calculations
   - Recalculate ramp time and total duration whenever a segment changes.
   - Use this logic:
   - Ramp minutes = absolute difference between current target and previous target divided by firing rate times 60, only when firing rate is greater than zero.
   - Total duration = sum of all ramp minutes plus all hold minutes.
   - Duration should be displayed as a derived field, not manually entered.

8. Graph preview
   - Add a live preview graph to the editor.
   - Use a small SVG or canvas implementation instead of a heavy charting library.
   - Compute graph points from ramp and hold segments using an ambient start temperature of 20 °C unless the firmware already has a better source for ambient.
   - Redraw on every segment edit.

9. Migration and backward compatibility
   - Ensure old saved programs can still be loaded.
   - When an old program is edited and saved, convert it to the new schema and new filename pattern.
   - Do not break existing kiln start logic that consumes program files.

10. Validation and finish
   - Test create, edit, reload, and save flows.
   - Verify generated filenames are unique and stable.
   - Verify duration and preview update correctly as segments are edited.
   - Verify saved JSON is valid and still usable by the firmware runtime.

**Agent Checklist**

Use this as the execution checklist.

1. Find the current program editor page assets and firmware save handler.
2. Document the current JSON shape and storage path.
3. Remove program_number from the UI.
4. Make program filenames auto-generated from name plus date.
5. Add collision-safe slug generation.
6. Add a program list endpoint.
7. Add a single-program fetch endpoint.
8. Add a create or update save endpoint.
9. Optionally add delete if low effort.
10. Build a lightweight program library page with New and Edit actions.
11. Build or refactor a plain JS editor page that supports create and edit modes.
12. Add dynamic segment add and remove behavior.
13. Compute per-segment ramp timing client-side.
14. Compute total duration client-side and show it read-only.
15. Save duration in the JSON payload automatically.
16. Add a live graph preview using SVG or canvas.
17. Load legacy program files without failing if program_number exists.
18. Strip program_number when saving edited legacy files.
19. Handle rename-on-save when name or created date changes.
20. Verify old and new program files still work with the kiln runtime.

**Acceptance Checklist**

The work is done only if all of these are true.

1. A user can open a list of saved firing programs.
2. A user can create a new program without entering a program number.
3. A user can open an existing program for editing.
4. A user can add and remove segments in the browser.
5. Total duration updates automatically as the program changes.
6. The preview graph updates automatically as the program changes.
7. Saving creates a JSON file with an automatic filename.
8. Editing an existing program updates the correct file, including rename behavior if needed.
9. Legacy files with program_number still load successfully.
10. Re-saved legacy files are converted to the new schema.
11. Saved files remain compatible with the firmware logic that starts firing programs.
12. The page stays lightweight and uses plain HTML, CSS, and JS only.

**Prompt For The External Agent**

Paste this as-is to the external agent:

```text
Implement a firing program library and editor for my standalone ESP32 kiln controller project.

Context:
- This project does not use Svelte or any frontend framework.
- The UI is plain HTML, CSS, and JavaScript served by the ESP32.
- Programs are stored as JSON files in SPIFFS.
- There is already an existing firing program page that manually creates a program and submits it to the firmware for saving.
- I want the new implementation to stay lightweight and simple, suitable for an ESP32-hosted web UI.

Goals:
- Add the ability to view saved programs.
- Add the ability to edit existing programs.
- Add a live preview graph of the firing profile.
- Remove the need for program_number.
- Generate program JSON filenames automatically.
- Calculate duration automatically.

Requirements:
- First inspect the current project and identify:
  - The existing firing program HTML, JS, and CSS files.
  - The firmware handlers or routes that save and load program files.
  - The current JSON schema and storage directory.
  - Whether the project uses SPIFFS or LittleFS.
- Keep legacy compatibility. If old files include program_number, they must still load.
- New and updated program files should use this schema:
  - name
  - created_date
  - duration
  - segments
- Each segment should use:
  - target_temperature
  - firing_rate
  - holding_time
- Remove program_number from the UI and from newly saved JSON.
- Use automatic filename generation based on a filesystem-safe slug from program name plus created_date.
- Avoid filename collisions by adding a numeric suffix when needed.
- If an existing program is edited and its name or created_date changes, handle file renaming safely.

Frontend expectations:
- Use plain HTML, CSS, and JS only.
- Create a lightweight program library page that lists saved programs and allows New and Edit.
- Create or refactor a program editor page that supports create mode and edit mode.
- Allow adding and removing segments dynamically.
- Show a read-only derived duration field.
- Add a live preview graph using lightweight SVG or canvas, not a heavy chart library.
- Recompute duration and graph data whenever segment inputs change.

Calculation rules:
- Use an ambient start temperature of 20 C unless the project already has a better configured ambient value.
- Ramp minutes = abs(target - previous_target) / firing_rate * 60 when firing_rate > 0.
- Total duration = sum of all ramp minutes plus all hold minutes.
- Duration should be saved automatically, not entered manually.

Firmware expectations:
- Add or adapt endpoints or handlers for:
  - listing saved programs
  - fetching one program
  - creating or updating a program
- Delete is optional if easy.
- The save handler should validate input and return the final saved id or slug.

Migration expectations:
- Legacy files with program_number must remain loadable.
- When a legacy program is edited and saved, remove program_number and save it in the new format.
- Do not break the firmware’s existing logic that consumes saved program files for firing.

Deliverables:
- Implement the feature end-to-end in the project.
- Summarize the routes, files, and handlers you changed.
- Explain the final JSON format.
- Note any assumptions you had to make.
- Report whether delete was implemented or intentionally deferred.

Acceptance criteria:
- I can view saved programs.
- I can create a new program without entering a program number.
- I can edit an existing program.
- Duration updates automatically.
- The preview graph updates automatically.
- Saved filenames are generated automatically.
- Legacy program files still load.
- Saved programs remain usable by the kiln controller runtime.

Do not introduce a frontend framework. Keep the solution simple, robust, and resource-conscious.
```

** Additional implementations **
- Have back and home buttons in the web UI
- Add IP address to CONFIG TFT subscreen

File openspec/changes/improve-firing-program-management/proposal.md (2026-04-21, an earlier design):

## Why

The kiln controller currently exposes a single manual-entry firing program page, which makes saved-program reuse, editing, and validation cumbersome. This change upgrades the operator experience with a lightweight program library and editor while preserving compatibility with existing program files and adding small navigation/status improvements that reduce friction on both the web UI and device UI.

## What Changes

- Replace manual program-number entry with a lightweight firing program library and editor flow.
- Add firmware-backed list, fetch, and save behavior for firing programs, with optional delete support if it fits the existing handlers cleanly.
- Standardize saved program data around `name`, `created_date`, `duration`, and `segments`, while keeping legacy files readable and converting them when re-saved.
- Generate filesystem-safe program identifiers automatically from program metadata and handle rename collisions safely.
- Add automatic duration calculation, dynamic segment editing, and a live firing-profile preview in the browser without introducing a frontend framework.
- Add consistent back and home navigation controls in the web UI.
- Show the current IP address on the CONFIG TFT subscreen so operators can discover the device address directly from the controller.

## Capabilities

### New Capabilities
- `firing-program-management`: Browse, create, edit, validate, and save firing programs through a lightweight library/editor workflow with legacy-file compatibility.
- `device-navigation-and-network-visibility`: Provide consistent back/home navigation in the UI and expose the active IP address on the CONFIG TFT subscreen.

### Modified Capabilities

None.

## Impact

- Web UI assets for firing program list/editor screens, shared navigation controls, and lightweight preview rendering.
- Firmware routes or handlers responsible for program storage, JSON validation, filename generation, and legacy-program normalization.
- Program files stored in SPIFFS or LittleFS, including rename-on-save behavior and metadata listing.
- TFT configuration-screen rendering for network visibility.

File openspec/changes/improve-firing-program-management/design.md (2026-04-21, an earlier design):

## Context

The current web UI exposes a single `data/firingProgram.html` form that posts multipart form data to `POST /program-editor`. The firmware handler in `lib/network/network.cpp` writes `/firingProgram_<programNumber>.json` files containing `name`, `duration`, `createdDate`, `segmentQuantity`, and `segments`, while the TFT workflow in `lib/gui/gui.cpp` loads programs back by numeric filename through `openProgram()`. The CONFIG TFT subscreen only exposes captive-portal controls, and the device IP address is only emitted to serial logs.

This change needs to modernize the program-management UX without introducing a frontend framework or breaking the kiln runtime’s ability to select and execute saved programs. It also needs to cover two smaller UX improvements: consistent back/home navigation in the web UI and direct IP visibility on the TFT config screen.

## Goals / Non-Goals

**Goals:**
- Introduce a lightweight program library and editor flow for saved firing programs.
- Replace manual program numbering with automatic, filesystem-safe identifiers.
- Persist canonical program JSON using the new schema while keeping legacy files loadable.
- Keep TFT program selection and runtime loading functional after the storage migration.
- Add derived duration and live profile preview in the editor with minimal client-side code.
- Add back/home navigation to secondary web UI screens and show the current IP address on the CONFIG TFT subscreen.

**Non-Goals:**
- Rewriting the web UI with a framework or heavy charting dependency.
- Changing kiln heat-control behavior, firing algorithms, or segment execution semantics.
- Requiring a one-time manual migration step before deployment.
- Committing to delete support as part of the initial contract if it complicates the existing handlers.

## Decisions

### 1. Split the firing-program experience into a library page and an editor page

The web UI will move from a single form page to two lightweight views: a library that lists saved programs and an editor that supports both create and edit flows. This keeps state management simple in plain HTML/JS and makes room for metadata listing, edit actions, and derived previews without overloading the existing form.

**Alternatives considered:**
- Extend the current single page with conditional modes. Rejected because it would mix list, edit, and save concerns in one static page and make navigation/state harder to reason about.
- Build a richer SPA-style client. Rejected because it adds complexity and weight that are not appropriate for an ESP32-hosted UI.

### 2. Store programs under canonical slug-based identifiers and maintain a program catalog

New and updated programs will be stored under filesystem-safe identifiers derived from program name plus created date, with collision-safe numeric suffixes. A lightweight catalog/manifest will track the saved programs and expose metadata for list/fetch/save operations.

This catalog becomes the stable bridge between the web UI, firmware APIs, and TFT program selection. It avoids forcing operators to manage numeric IDs while keeping a deterministic lookup surface for the rest of the system.

**Alternatives considered:**
- Keep numeric filenames as the canonical format. Rejected because it preserves the UX problem the change is trying to remove.
- Use raw names as filenames. Rejected because names are not filesystem-safe or collision-safe.

### 3. Normalize program data at the firmware boundary

The save path will validate and normalize incoming payloads into a canonical schema:
- `name`
- `created_date`
- `duration`
- `segments`

Each segment will be saved as:
- `target_temperature`
- `firing_rate`
- `holding_time`

The loader will accept legacy shapes such as `createdDate`, `segmentQuantity`, camelCase segment fields, and `program_number`/`programNumber`, then normalize them into the in-memory representation. Re-saved legacy programs will be written back only in the canonical schema.

**Alternatives considered:**
- Keep mixed old/new field names indefinitely. Rejected because it makes the data contract ambiguous and increases maintenance cost.
- Migrate all legacy files eagerly on boot. Rejected because it adds risk and unnecessary write amplification.

### 4. Preserve runtime compatibility by selecting programs through catalog entries rather than filename conventions

The TFT program-selection flow currently stores a numeric preference and loads `/firingProgram_<programNumber>.json` directly. Instead of preserving that filename convention, the TFT flow will resolve the selected entry through the catalog and then load the referenced program file. Existing legacy files remain selectable because the catalog builder will include both legacy and canonical files.

This keeps the runtime compatible with saved programs after migration while allowing the storage format to evolve independently of the old numbering scheme.

**Alternatives considered:**
- Dual-write legacy numeric aliases for every new save. Rejected because alias files can drift and create unclear source-of-truth behavior.
- Remove TFT program selection from scope. Rejected because the proposal explicitly requires saved programs to remain usable by the kiln runtime.

### 5. Derive duration and preview client-side, then verify duration on save

The editor will recompute ramp time, total duration, and SVG/canvas preview points whenever segment inputs change. The firmware save handler will still validate payload shape and recompute or verify the submitted duration before persisting, so malformed or stale client data cannot become the source of truth.

**Alternatives considered:**
- Compute duration only on the server. Rejected because the editor would lose immediate feedback.
- Trust the client’s duration completely. Rejected because it weakens validation and migration safety.

### 6. Surface navigation and network visibility with minimal shared UI helpers

Secondary web pages will expose explicit Back and Home controls using the existing plain HTML/JS/CSS structure. The CONFIG TFT screen will render the active IP address from station mode (`WiFi.localIP()`) or captive portal/AP mode (`WiFi.softAPIP()`), and it will show an unavailable state when no address is active.

**Alternatives considered:**
- Keep navigation implicit through browser history only. Rejected because these pages are often used on mobile devices or captive-portal flows where explicit navigation is clearer.
- Leave IP visibility to serial logs. Rejected because operators need the address directly on the device.

## Risks / Trade-offs

- **Catalog drift between files and metadata** -> Rebuild or refresh catalog entries during save/load operations and prefer deriving catalog contents from actual program files when possible.
- **Rename collisions or interrupted updates** -> Use deterministic slug generation, collision suffixing, and replace-on-success semantics when renaming an existing program.
- **Legacy schema variants causing partial loads** -> Centralize normalization so both web and TFT paths share the same compatibility rules.
- **Preview logic adding browser overhead** -> Keep the graph implementation to simple SVG/canvas primitives and update only on editor input changes.

## Migration Plan

1. Add program-catalog and normalization helpers that can enumerate existing program files and read both legacy and canonical schemas.
2. Introduce list/fetch/save firmware handlers backed by the catalog while keeping old program files readable.
3. Update TFT selection/loading to resolve through catalog entries instead of assuming numeric filenames.
4. Replace the current program form with library/editor pages, derived duration, preview rendering, and shared back/home controls.
5. Expose IP information on the CONFIG TFT subscreen.

Rollback relies on two safeguards: legacy files remain untouched until a program is edited and re-saved, and the compatibility loader continues to understand legacy data. If the new UI or catalog flow needs to be reverted, the system still has access to the original program files.

## Open Questions

None blocking. Delete support remains intentionally optional and can be implemented only if it fits the existing handlers without expanding the compatibility surface.

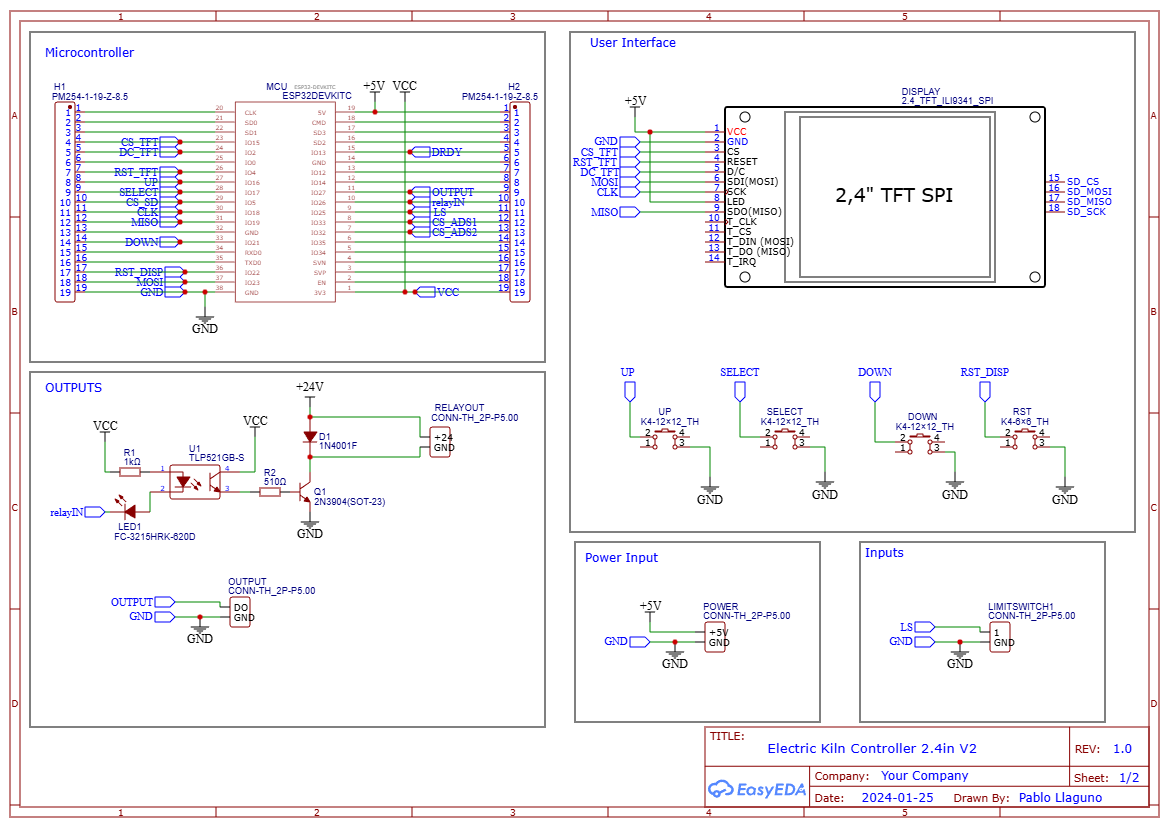
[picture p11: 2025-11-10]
hardware/PCB/ADS1220 versions/2.4in display NEW/Schematic_Electric-Kiln-Controller_Sheet1.png

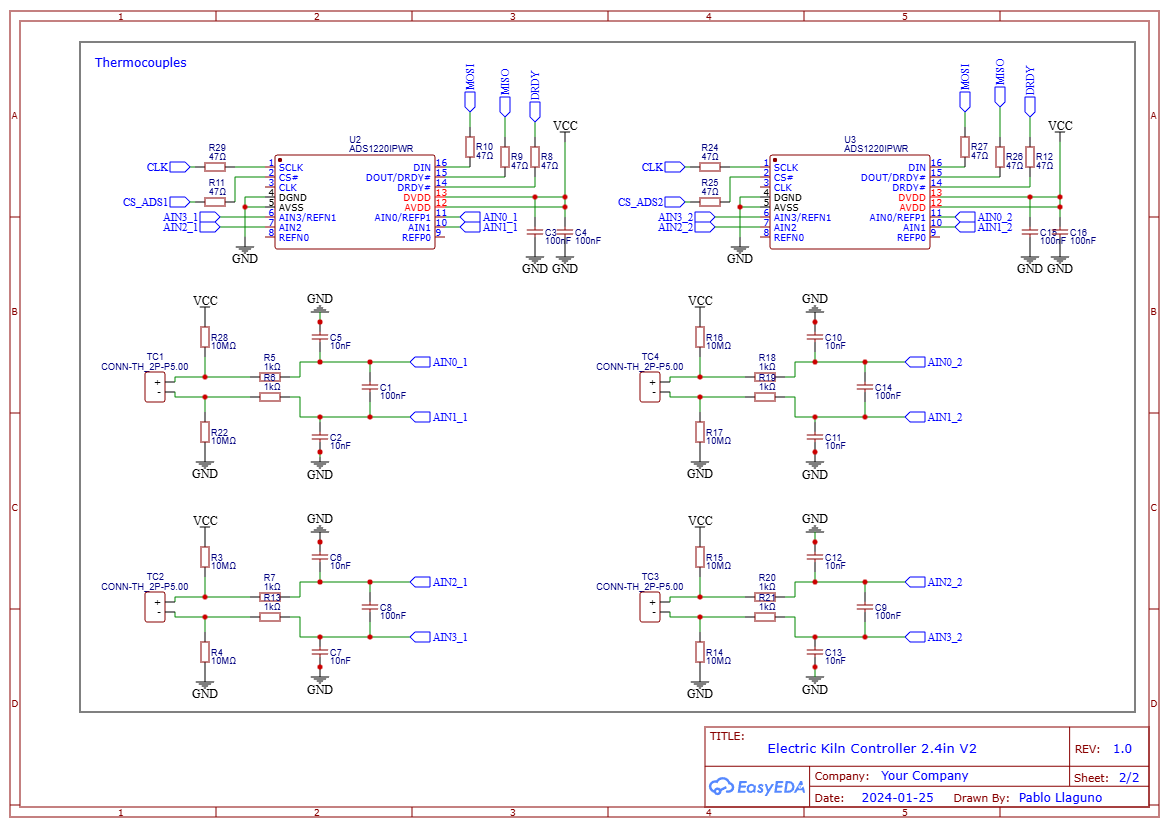
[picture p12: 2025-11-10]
hardware/PCB/ADS1220 versions/2.4in display NEW/Schematic_Electric-Kiln-Controller_Sheet2.png

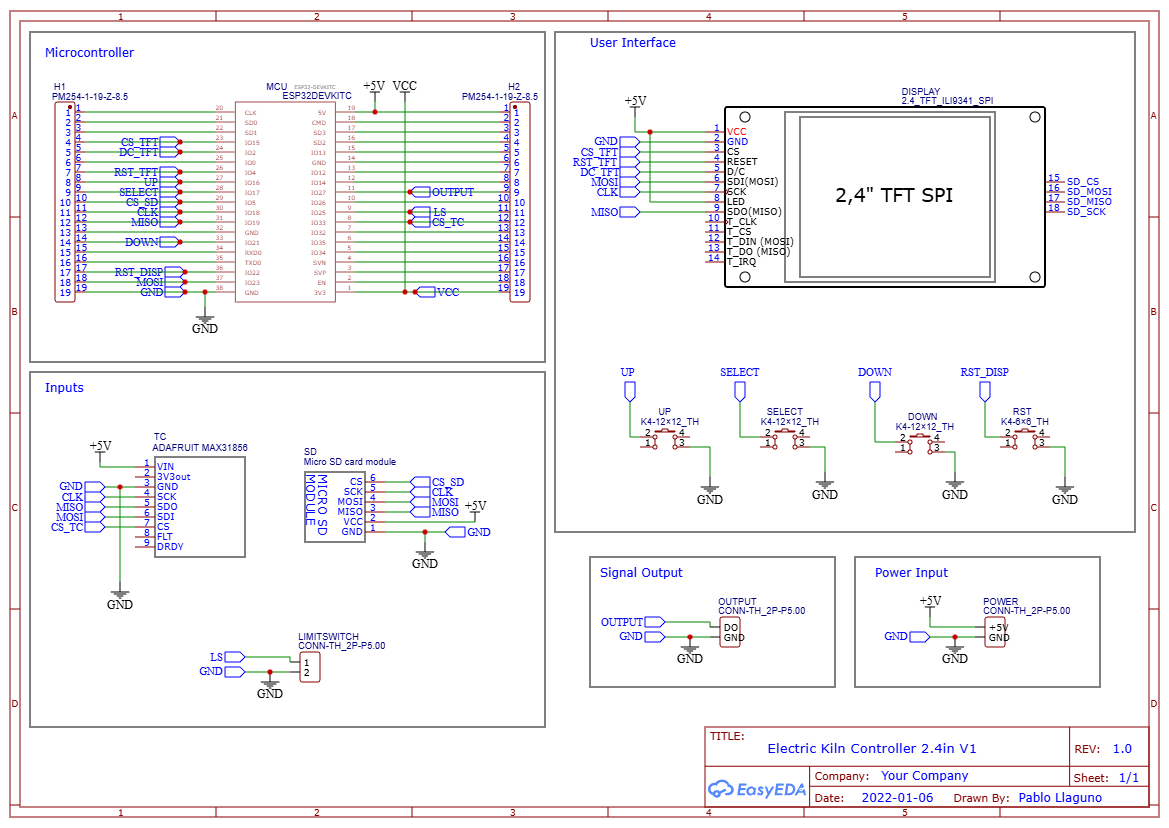
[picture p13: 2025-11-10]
hardware/PCB/MAX31856 versions/2.4in display/Schematic_Electric-Kiln-Controller.png

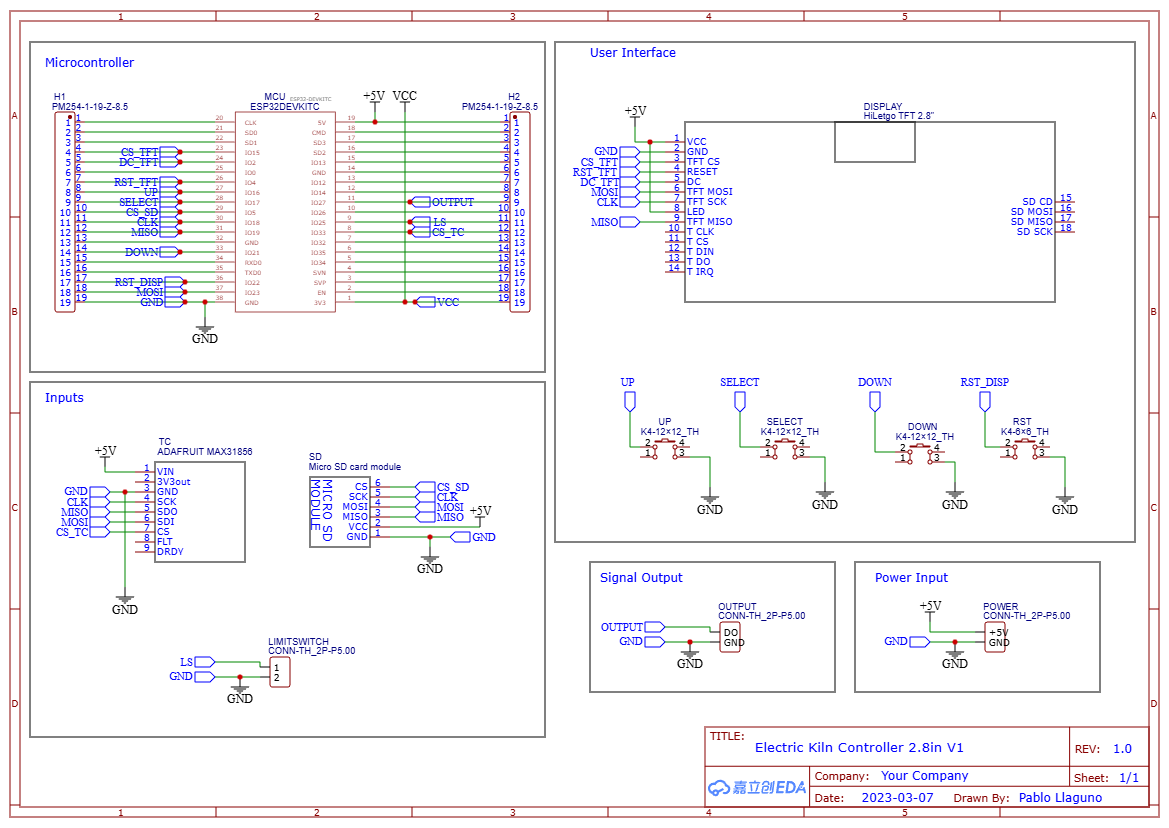
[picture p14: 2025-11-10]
hardware/PCB/MAX31856 versions/2.8in display/Schematic_Electric-Kiln-Controller.png

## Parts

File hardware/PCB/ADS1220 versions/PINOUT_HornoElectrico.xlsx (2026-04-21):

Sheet: ESP32 PINOUT
INPUT STATE | OUTPUT STATE | GPIO | INPUT | OUTPUT | Notes | adc | Components
OCUPADO | LIBRE | 0 | Pulled Up | OK | outputs PWM at boot | x |  | https://randomnerdtutorials.com/esp32-pinout-reference-gpios/
OCUPADO | LIBRE | 1 | TX pin | OK | debug output at boot |  |  | https://diyprojects.io/esp32-gpio-pins-and-associated-functions-i-o-pwm-rtc-i2c-spi-adc-dac/
OCUPADO | OCUPADO | 2 | OK | OK | connected to onboard LED | x | TFT SPI DC | https://www.youtube.com/watch?v=LY-1DHTxRAk
LIBRE | OCUPADO | 3 | OK | RX-pin | HIGH at boot
OCUPADO | OCUPADO | 4 | OK | OK |  | x | TFT RST pin
LIBRE | LIBRE | 5 | OK | OK | outputs PWM at boot
OCUPADO | OCUPADO | 6 | x | x | connected to integrated SPI flash
OCUPADO | OCUPADO | 7 | x | x | connected to integrated SPI flash
OCUPADO | OCUPADO | 8 | x | x | connected to integrated SPI flash
OCUPADO | OCUPADO | 9 | x | x | connected to integrated SPI flash
OCUPADO | OCUPADO | 10 | x | x | connected to integrated SPI flash
OCUPADO | OCUPADO | 11 | x | x | connected to integrated SPI flash
LIBRE | LIBRE | 12 | OK | OK | boot fail if pulled high | x
OCUPADO | OCUPADO | 13 | OK | OK |  | x | ADS DRDY
LIBRE | LIBRE | 14 | OK | OK | outputs PWM at boot | x
OCUPADO | OCUPADO | 15 | OK | OK | outputs PWM at boot | x | TFT SPI CS
OCUPADO | OCUPADO | 16 | OK | OK |  |  | upPin
OCUPADO | OCUPADO | 17 | OK | OK |  |  | selectPin
OCUPADO | OCUPADO | 18 | OK | OK |  |  | SPI CLK
OCUPADO | OCUPADO | 19 | OK | OK |  |  | SPI MISO
OCUPADO | OCUPADO | 21 | OK | OK |  |  | downPin
OCUPADO | OCUPADO | 22 | OK | OK |  |  | Reset button
OCUPADO | OCUPADO | 23 | OK | OK |  |  | SPI MOSI
OCUPADO | OCUPADO | 25 | OK | OK |  | x | Limit Switch
OCUPADO | OCUPADO | 26 | OK | OK |  | x | Relay pin
OCUPADO | OCUPADO | 27 | OK | OK |  | x | Heater Pin
LIBRE | LIBRE | 32 | OK | OK |  | x
OCUPADO | OCUPADO | 33 | OK | OK |  |  | ADS CS
LIBRE | OCUPADO | 34 | OK | x | input only | x
LIBRE | OCUPADO | 35 | OK | x | input only | x
LIBRE | OCUPADO | 36/SP | OK | x | input only | x
LIBRE | OCUPADO | 39/SN | OK | x | input only | x
 | INPUTS RESTANTES | 9
 | OUTPUTS RESTANTES | 6

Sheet: POWER CONSUMPTION
Part | Voltage | Power (W) | Units | Regulator needed
SSRs | 12V | 0.24 | 3 | No
ESP32 | 3.3V | 1 | 1 | Yes
Fan | 12V | 3 | 1 | No
DPT | 12V | 0.24 | 4 | No
TFT | 3.3V |  |  | Yes
 | Total Power | 5.68 | watts

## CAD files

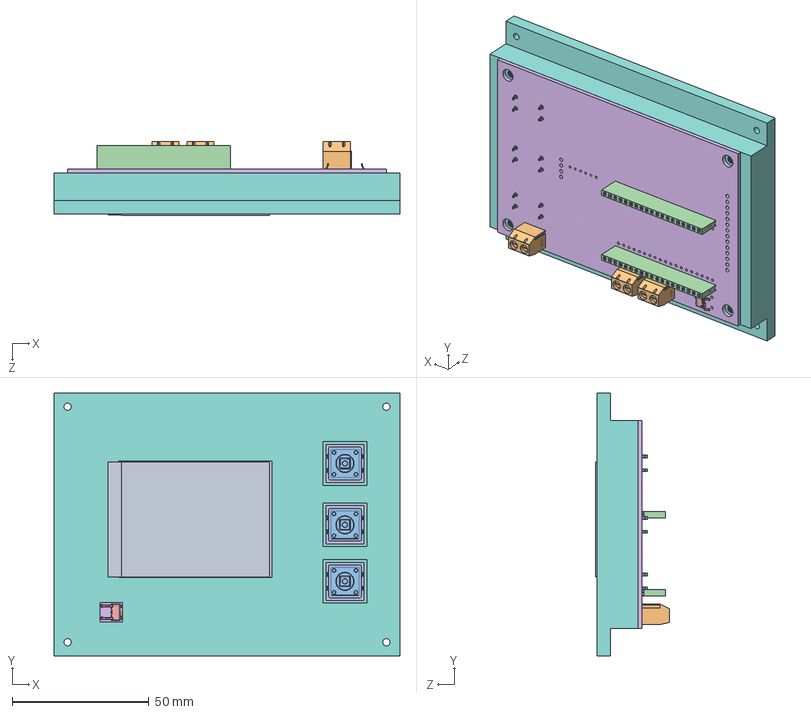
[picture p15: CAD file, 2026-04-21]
hardware/PCB/MAX31856 versions/3D files case/pcb.SLDASM
126.7 x 96.2 x 27.1 mm
SOLID.step x 3
COMPOUND.step x 3
SOLID-0.step x 2
Board.step
tft2.4
dispHeader
Case

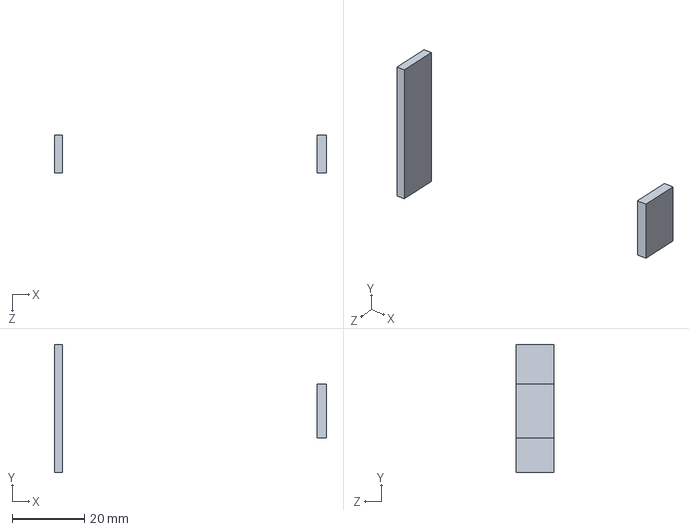
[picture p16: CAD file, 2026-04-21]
hardware/PCB/MAX31856 versions/3D files case/dispHeader.SLDPRT
75.5 x 35.6 x 10.5 mm

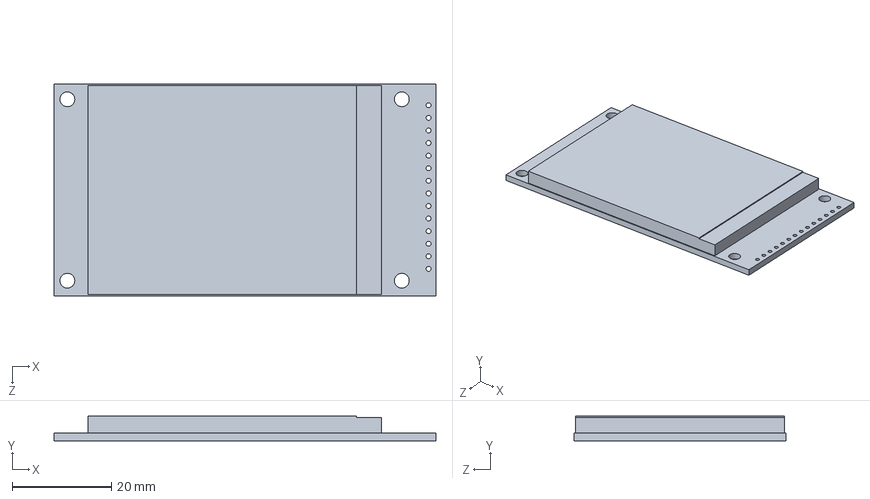
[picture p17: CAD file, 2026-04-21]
hardware/PCB/MAX31856 versions/3D files case/tft2.4.SLDPRT
77.1 x 5.00 x 42.7 mm

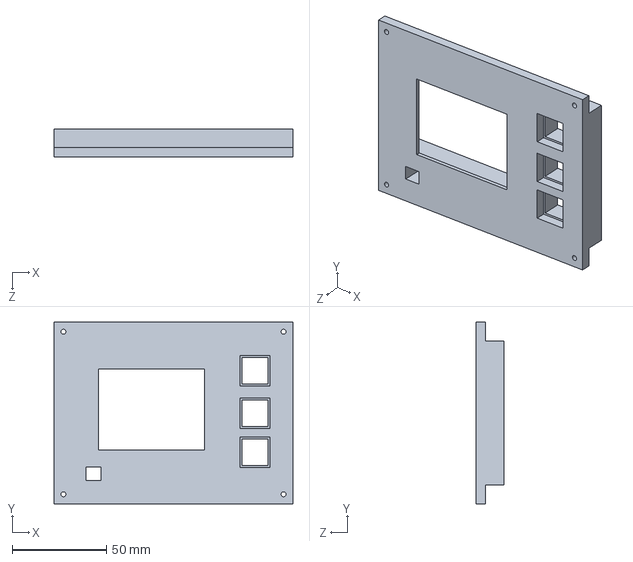
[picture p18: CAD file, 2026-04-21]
hardware/PCB/MAX31856 versions/3D files case/Case.SLDPRT
126.7 x 96.2 x 15.0 mm

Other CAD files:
hardware/PCB/MAX31856 versions/3D files case/Case.STL

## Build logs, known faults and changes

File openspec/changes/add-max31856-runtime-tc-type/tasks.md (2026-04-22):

## 1. Driver selection and shared thermocouple state

- [x] 1.1 Add build-time thermocouple-driver selection in `src/userSetup.h` for ADS1220 vs MAX31856, including any driver-specific pin/configuration constants that must stay aligned with existing hardware settings
- [x] 1.2 Add shared runtime thermocouple-type state and persistence bootstrapping so the firmware starts from the stored type when present and otherwise seeds from the configured default

## 2. Sensor task thermocouple support

- [x] 2.1 Integrate MAX31856 initialization and temperature-reading support into `lib/task/sensor_task.cpp` while preserving the existing ADS1220 path
- [x] 2.2 Implement driver-specific runtime thermocouple-type application logic for both ADS1220 and MAX31856, including explicit error handling for unsupported or failed type application
- [x] 2.3 Ensure thermocouple driver initialization and runtime type changes surface clear fault or initialization feedback instead of silently coercing to another type

## 3. TFT CONFIG thermocouple-type flow

- [x] 3.1 Extend the CONFIG TFT submenu in `lib/gui/gui.cpp` with a `Change TC Type` option and adjust selection bounds/navigation accordingly
- [x] 3.2 Add a dedicated thermocouple-type selection subscreen that uses the existing up/down/select interaction model to browse and confirm available thermocouple types
- [x] 3.3 Render the actively toggled thermocouple-type value in orange and persist the confirmed selection through the existing `Preferences` flow

## 4. Verification

- [x] 4.1 Verify both build configurations still compile cleanly and the existing ADS1220 path remains functional after introducing MAX31856 support
- [x] 4.2 Verify runtime thermocouple-type changes are applied after confirmation, survive restart, and surface clear errors when the configured driver cannot use the selected type
- [x] 4.3 Verify the TFT CONFIG flow enters and exits the new thermocouple-type screen correctly and shows the orange active-selection state while browsing

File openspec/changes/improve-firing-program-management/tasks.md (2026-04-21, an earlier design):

## 1. Program storage and compatibility

- [ ] 1.1 Add program catalog and normalization helpers that can enumerate saved programs and read both legacy and canonical JSON shapes
- [ ] 1.2 Implement automatic slug generation, collision-safe naming, and rename-on-save behavior for firing program files
- [ ] 1.3 Add firmware handlers for listing saved program metadata, fetching a saved program by identifier, and creating or updating a program
- [ ] 1.4 Validate incoming program payloads in the save path and recompute or verify derived duration before persisting
- [ ] 1.5 Update the kiln runtime/TFT program-selection flow to resolve saved programs through the catalog instead of numeric filename assumptions

## 2. Web UI program management

- [ ] 2.1 Create a lightweight firing program library page that lists saved programs and exposes New and Edit actions
- [ ] 2.2 Refactor the firing program editor into create and edit modes with canonical program fields and dynamic segment add/remove behavior
- [ ] 2.3 Add client-side duration calculation and a read-only derived duration display in the editor
- [ ] 2.4 Add a lightweight live firing-profile preview using SVG or canvas and refresh it on segment edits
- [ ] 2.5 Add consistent Back and Home controls to the program-management pages and other secondary web UI screens that share the navigation pattern

## 3. Device UI updates and verification

- [ ] 3.1 Update the CONFIG TFT subscreen to display the active station or captive-portal IP address, with an unavailable fallback
- [ ] 3.2 Confirm legacy saved programs still load in the editor and remain usable by the kiln runtime after re-save
- [ ] 3.3 Confirm new-format programs can be created, edited, renamed, reloaded, and executed with correct duration and preview behavior

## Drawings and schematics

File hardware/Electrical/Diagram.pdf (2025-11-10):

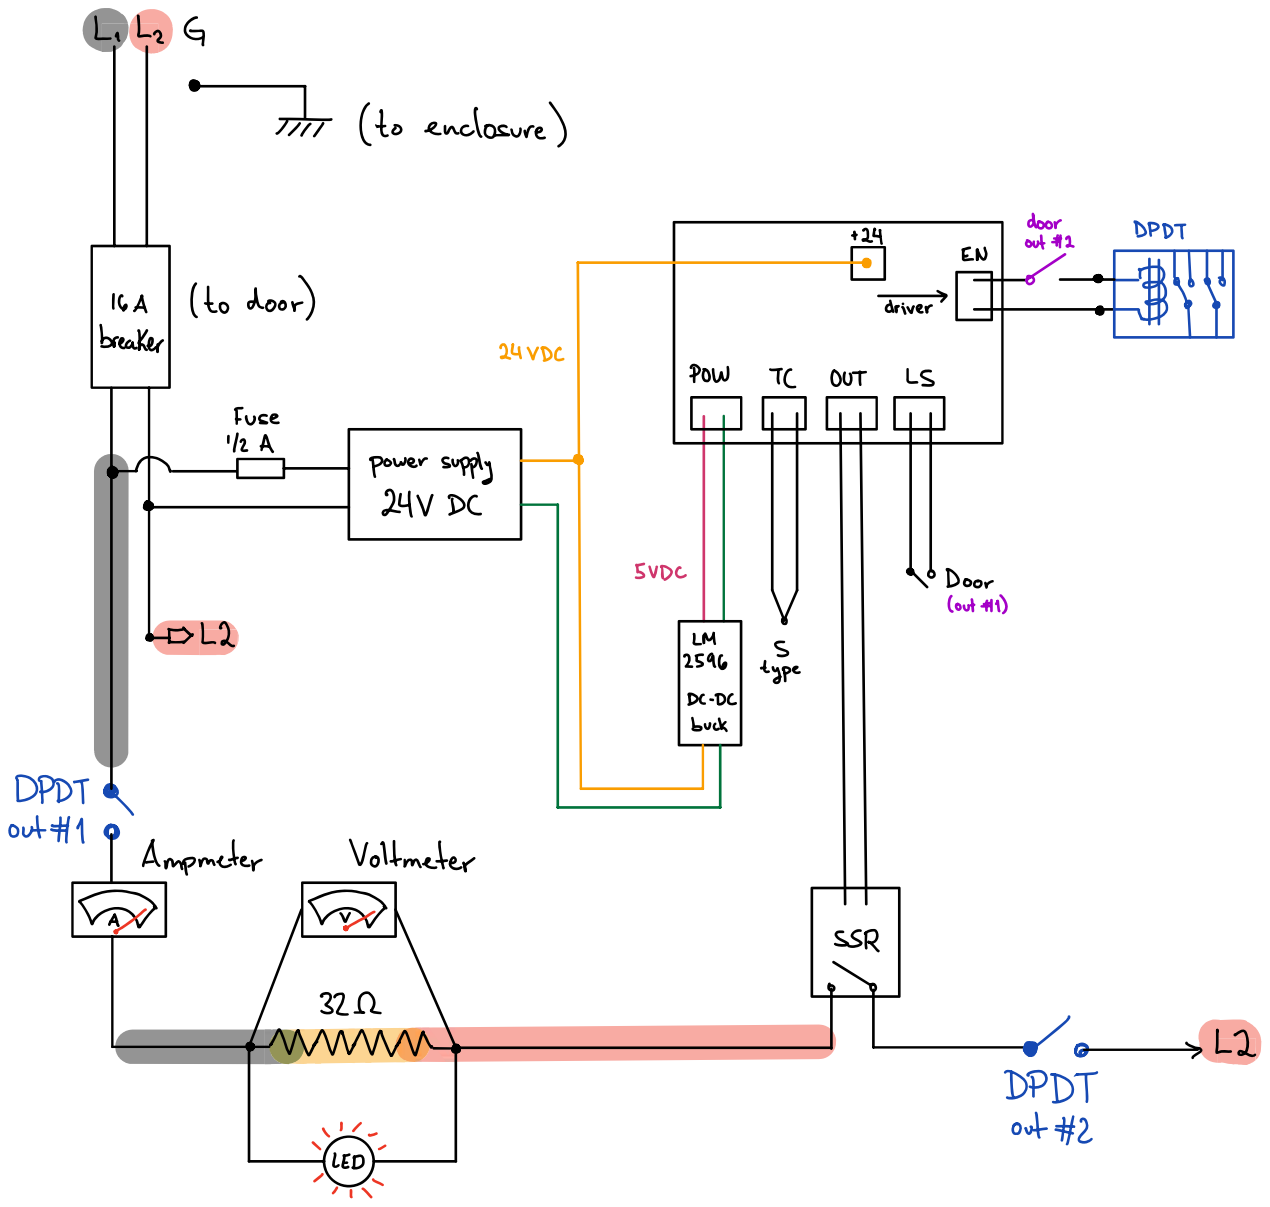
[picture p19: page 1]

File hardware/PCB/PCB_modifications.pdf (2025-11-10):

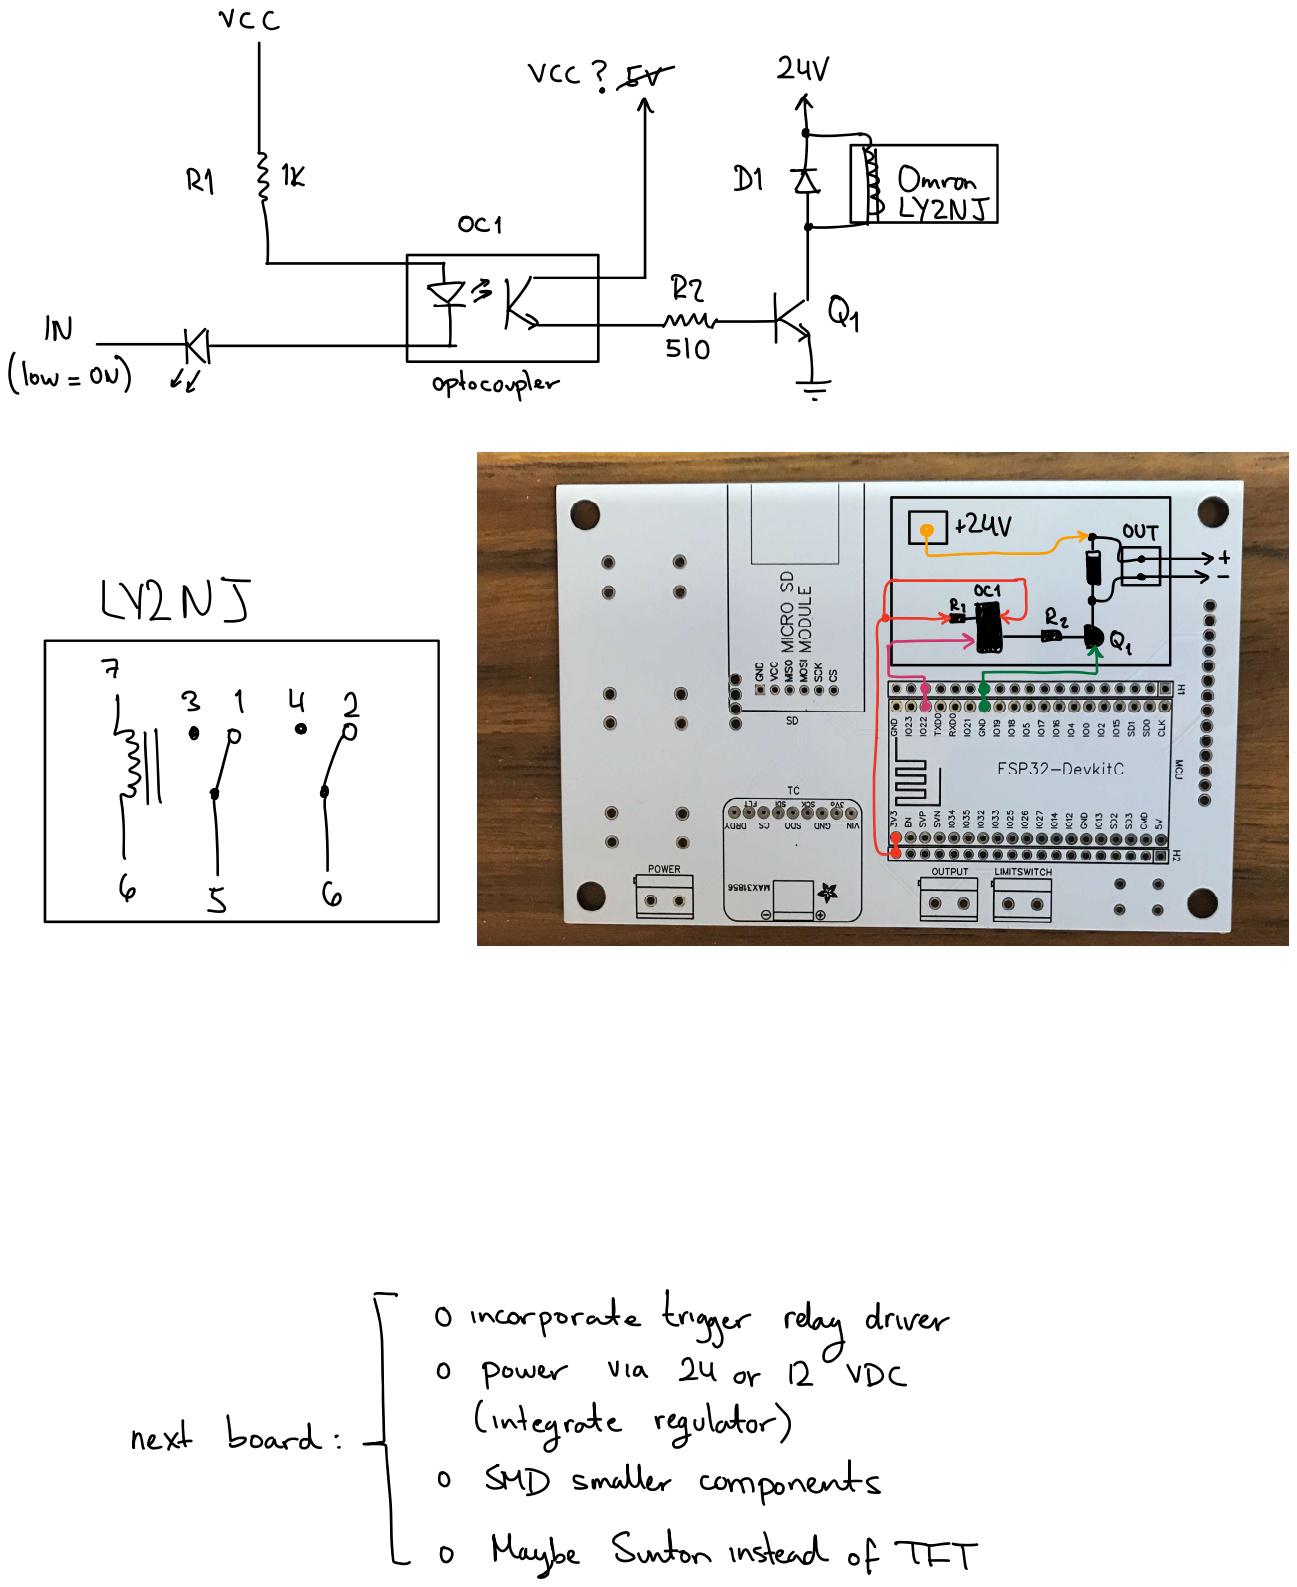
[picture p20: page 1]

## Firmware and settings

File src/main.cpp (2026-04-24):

#include <Arduino.h>
#include <Wire.h>
#include <SPI.h>               
#include <SPIFFS.h>    

#include "userSetup.h"      // Setup user variables (CHANGE THESE IN HEADER FILE)
#include "common.h"         // Common variables and functions

#include "gui/gui.h"            // Graphical user interface source file
#include "control/heat_controller.h"   // PID and heating control code
#include "network/network.h"        // WiFi and Server related code
#include "ota/ota.h"       // OTA firmware update task
#include "telemetry/telemetry.h"  // Influx DB publishing task
#include "sensors/sensors.h"    // Thermocouple reading task

// global (shared) variables definition
double g_pidInput;
double g_pidOutput;
double g_pidSetPoint;
int g_segNum;
bool g_connected;
bool g_connecting;
bool g_published;
char g_tcType;
bool g_tcInitialized;
String g_errMsg;
bool g_tcFault;
uint8_t g_tcFaultCode;

// External objects initialization
FiringProgram currentProgram;
InfluxDbConfig g_influxConfig;
OtaStatus g_ota_status = OtaStatus::IDLE;
String g_ota_latest_version;
String g_ota_latest_tag;
SemaphoreHandle_t mutex = xSemaphoreCreateMutex();
SemaphoreHandle_t disp_mutex = xSemaphoreCreateMutex();
SemaphoreHandle_t g_spiMutex = xSemaphoreCreateMutex();
HeatController controller(mutex);
Network network(mutex, SPIFFS);

// put function declarations here:
void main_task(void* parameter);
void resetCheck();

void setup() {
  Serial.begin(115200);
  SPI.begin();

  delay(1500);
  gui_start(); // also seeds g_tcType from preferences (falls back to TC_DEFAULT_TYPE)

  // Mount SPIFFS file system
  while (!SPIFFS.begin(true)) {
    disp_error_msg("SPIFFS Error", "Can't setup file system.", "Make sure files are uploaded.");
    if (digitalRead(rstPin) == LOW) esp_restart();
    delay(200);
  }

  // Load WiFi credentials
  network.loadWifiCredentials();
  // Load InfluxDB credentials
  network.loadInfluxDbCredentials();

  // Pin modes
  pinMode(heaterPin, OUTPUT);
  pinMode(relayPin, OUTPUT);
  pinMode(limitSwitchPin, INPUT_PULLUP); // should it be an interrupt?
  
  // Create the main task and set its affinity to core 1
  xTaskCreatePinnedToCore(main_task, "Main", 8192, NULL, 1, NULL, 1);
  // Create the sensor task and set its affinity to core 1
  xTaskCreatePinnedToCore(sensor_task, "Sensor", 8192, NULL, 1, NULL, 1); 
  // Create the telemetry task and set its affinity to core 0
  xTaskCreatePinnedToCore(telemetry_task, "Telemetry", 32768, NULL, 1, NULL, 0);
  // Create the OTA task and set its affinity to core 0
  xTaskCreatePinnedToCore(ota_task, "OTA", 32768, NULL, 1, NULL, 0);

  log_i("Total heap: %d", ESP.getHeapSize());
  log_i("Free heap: %d", ESP.getFreeHeap());
}

// Task function to perform main Kiln control on core 1
void main_task(void* parameter) {

  while (1) {
    
    controller.run();
    
    gui_run();

  }
}

//*******************************************************************************************************************************

void loop() {
  vTaskDelay(10);
}

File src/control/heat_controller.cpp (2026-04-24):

#include "heat_controller.h"

HeatController::HeatController(SemaphoreHandle_t &mutex) 
: mutex(mutex),
  pidCont(&pidInput, &pidOutput, &pidSetPoint, Kp, Ki, Kd, DIRECT) {
}

void HeatController::run() {
  safetyCheck();

  // Do heating cycle if there is a segment to run
  if (segNum >= 1) {
    checkDoor();
    updatePIDs();
    adjustHeat();
    updateSeg();
    if (SIMULATION) logData();
  }
  else {
    digitalWrite(relayPin, HIGH); 
  }

  // Synchonize shared task variables
  xSemaphoreTake(mutex, portMAX_DELAY);  // Wait for the semaphore to become available
  pidInput = g_pidInput;
  fault = g_tcFault;
  g_pidOutput = pidOutput;
  g_pidSetPoint = pidSetPoint;
  g_segNum = segNum;
  xSemaphoreGive(mutex);  // Release the semaphore
}

// adjustHeat: CONTROL THE HEATING ELEMENT
void HeatController::adjustHeat() {
  if (millis() - heatStart >= heatingCycle) { 
    heatStart = millis();
  } 
  // door must be closed
  if (!doorClosed) {
    digitalWrite(relayPin, HIGH);  // disconnect power
    return;
  }

  digitalWrite(relayPin, LOW); // enable power
  if (pidOutput * heatingCycle >= millis() - heatStart) {
    digitalWrite(heaterPin, HIGH);
  } else {
    digitalWrite(heaterPin, LOW);
  }
}

//  SHUTDOWN: SHUT DOWN SYSTEM
void HeatController::shutDown() {
  // Disconnect power
  digitalWrite(relayPin, HIGH);
  // Turn off heating element relay
  digitalWrite(heaterPin, LOW);
  // Turn off PID algorithm
  setupPIDs(LOW);
}

// SAFETYCHECK: CHECK IF TEMP IS TOO HIGH
void HeatController::safetyCheck() {
  if (fault) {
    shutDown();
    disp_error_msg("Thermocouple Error", "System was shut down", "Press RESET to restart");
    while (1) { // or while fault?
      if (digitalRead(rstPin) == LOW)
        esp_restart();
    }
  }

  if (pidInput >= maxTemp) {
    shutDown();
    disp_error_msg("MAX TEMP REACHED", "System was shut down.",
                  "Press RESET to restart.");
    while (1) {
      if (digitalRead(rstPin) == LOW)
        esp_restart();
    }
  }
}

//  CHECKDOORISR: CHECK DOOR
void HeatController::checkDoor() {
  doorClosed_before = doorClosed;            // save previous door state
  if (digitalRead(limitSwitchPin) == LOW) {  // check new door state
    doorClosed = true;                       // door closed
  } else doorClosed = false;                 // door open

  // Resume time measurements in PID algorithm
  if (!doorClosed_before && doorClosed && segNum >= 1) {  // only if door was opened and now it's closed (and firing)
    if (!isOnHold) {
      rampStart = millis() - (lastRampHours * 3600000);
      double newRampHours = (millis() - rampStart) / 3600000.0;
      // log_i("new rampHours: %.6f \n", newRampHours);
    } else {
      holdStart = millis() - (lastHoldMins * 60000);
      holdMins = (millis() - holdStart) / 60000.0;
      // log_i("holdMins: %.0f \n", holdMins);
    }
  }
}

//  UPDATEPIDS: UPDATE THE PID LOOPS
void HeatController::updatePIDs() {
  // Update the PID controller based on new variables 
  pidCont.Compute();  // (internally it will only compute if sample time has been elapsed)

  if (firingMode == FiringModes::manual) {
    pidSetPoint = manualSetPoint;
    return;
  }

  static double calcSetPoint;   // Calculated set point (degrees)

  // If door is open, exit and save ramp time (hold time saved in updateSeg)
  if (!doorClosed) {
    // If before it was closed, pause ramp time measurement (when ramping)
    if (doorClosed_before && !isOnHold) {
      lastRampHours = (millis() - rampStart) / 3600000.0;
      // log_i("lastRampHours saved. last rampHours: %.6f \n", lastRampHours);
    }
    return;
  }

  // Get the last target temperature
  if (segNum != 1) lastTemp = currentProgram.segments[segNum - 2].targetTemperature;
  // Calculate the new setpoint value.  Don't set above / below target temp
  if (isOnHold == false) {
    // Ramp: measure spanned t and calculate the SP with it
    if(SIMULATION) rampHours = (millis() - rampStart) * alpha / 3600000.0;
    else rampHours = (millis() - rampStart) / 3600000.0;
    calcSetPoint = lastTemp + (currentProgram.segments[segNum - 1].firingRate * rampHours);
    // fix SP to target temp in case it's more than target temp
    if (currentProgram.segments[segNum - 1].firingRate >= 0 && calcSetPoint >= currentProgram.segments[segNum - 1].targetTemperature) {
      calcSetPoint = currentProgram.segments[segNum - 1].targetTemperature;
    }
    if (currentProgram.segments[segNum - 1].firingRate < 0 && calcSetPoint <= currentProgram.segments[segNum - 1].targetTemperature) {
      calcSetPoint = currentProgram.segments[segNum - 1].targetTemperature;
    }
  } 
  else {
    calcSetPoint = currentProgram.segments[segNum - 1].targetTemperature;  // Hold
  }
  // Set the target temp.
  pidSetPoint = calcSetPoint;
}

//  UPDATESEG: UPDATE THE PHASE AND SEGMENT
void HeatController::updateSeg() {

  // No need to update if not in auto mode
  if (firingMode == FiringModes::manual) {
    return;
  }

  // If door is closed, start hold phase or move to next segment (do I really want this??? what if ramp is negative, opening = cooling)
  if (doorClosed) {
    // Start the hold phase if temp is in range
    if ((!isOnHold && currentProgram.segments[segNum - 1].firingRate < 0 && pidInput <= (currentProgram.segments[segNum - 1].targetTemperature + tempRange)) ||   // if ramp is negative
        (!isOnHold && currentProgram.segments[segNum - 1].firingRate >= 0 && pidInput >= (currentProgram.segments[segNum - 1].targetTemperature - tempRange))) {  // if ramp is positive
      isOnHold = true;
      holdStart = millis();
    }
    // Go to the next segment if holding and hold time is completed
    if (isOnHold) {
      if (SIMULATION) holdMins = (millis() - holdStart) * alpha / 60000.0;
      else holdMins = (millis() - holdStart) / 60000.0;
      if (holdMins >= currentProgram.segments[segNum-1].holdingTime) {
        segNum += 1;
        isOnHold = false;
        rampStart = millis();
      }
    }
  }
  // If door has just been opened (perhaps implement similar method to lastTemp = pidInput;)
  if (!doorClosed && doorClosed_before) {
    lastHoldMins = (millis() - holdStart) / 60000.0;
    // log_i("lastHoldMins saved. last holdMins: %.0f \n", lastHoldMins);
  }

  // Check if complete -> turn off all zones
  if (segNum > currentProgram.segmentQuantity) {
    shutDown();
    goToIntroScreen();
    segNum = 0; 
  }
}
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

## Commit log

2024-01-10 More organized (folder structure + classes). However, lots of include errors and concurrency issues.
    [gui.cpp, main.cpp, userSetup.h]
2024-01-15 circular dependencies fixed (ugly but compiles)
    [main.cpp, userSetup.h]
2024-01-23 Fixed issues, added some webserver functionality
    [main.cpp, userSetup.h]
2024-01-26 Added thermocouple and fixed some bugs
    [thermocouple_table_k.csv, thermocouple_table_r.csv, thermocouple_table_s.csv]
2024-01-31 Configured for ADS1220. Fixed some bugs
    [main.cpp, userSetup.h]
2024-02-02 Fixed influx reconnection uses. GUI now uses Strings instead of char arrays
    [main.cpp]
2024-05-15 Fixed network exception error, minor code movements also
    [main.cpp]
2024-06-05 Simplified database. Fixed SPequalPV
    [main.cpp]
2024-06-17 Added simulation capability. Move to next segment bug fixed. Changed fault warning. Simplified reset check
    [userSetup.h]
2025-11-09 Ported API token to secrets file. Added better README, drawio task diagram, removed unnecesary files. Changed simulation logic.
    For simulation: in sensor_task.cpp the sampling period and the simulation algorithm (FOPDT) now don't scale with alpha. Instead on heat_control.cpp the methods updatePIDs() and updateSeg() use alpha 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
2025-11-10 Added PCB and Electrical documentation.
2025-11-11 Added thermocouple optimization subproject (jupyter notebook)
    [thermocouple_table_k.csv, thermocouple_table_r.csv, thermocouple_table_s.csv]
2026-03-15 feat: configure InfluxDB credentials via captive portal web UI
    - Add InfluxDbConfig struct to common.h; define g_influxConfig global
    - Add loadInfluxDbCredentials() / saveInfluxDbCredentials() to Network class;
    save/load /influxdb_credentials.json on SPIFFS (mirrors WiFi credential pattern)
    - Add GET /influxdb-manager, GET /getInfluxCredentials (token stripped),
    POST /influxdb-manager routes to the config web server
    - Create data/influxdb-manager.html form (URL, Token, Org, Bucket, Timezone)
    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
2026-03-15 feat: OTA firmware updates via captive portal + GitHub Releases CI
    - Add firmware update page at /firmware-update with version check and
    one-click update UI
    - New FreeRTOS ota_task (core 0, 32KB stack) handles all blocking OTA
    operations; state machine (IDLE/CHECKING/UPDATE_AVAILABLE/UP_TO_DATE/
    UPDATING/ERROR) keeps the async web server unblocked
    - Check: hits api.github.com/repos/pllagunos/ElectricKiln/releases/latest
    over HTTPS (Sectigo CA cert embedded); compares release name to
    OTA_VERSION build define
    - Update: streams firmware binary via HTTPClient + Update.writeStream(),
    calls ESP.restart() on success
    - 4 new web routes: GET /firmware-update, GET /getFirmwareStatus,
    POS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
    [main.cpp]
2026-03-15 fix: remove dead secrets.h include from userSetup.h and CI step
    Since InfluxDB credentials moved to runtime SPIFFS config, the macros
    defined in secrets.h (INFLUXDB_URL, INFLUXDB_TOKEN, etc.) are no longer
    referenced anywhere in the codebase. Removing the include from
    userSetup.h makes secrets.h fully dead, which in turn removes the need
    for the CI workaround that created a dummy copy of the file.
    [userSetup.h]
2026-04-21 Changed README substantially. Added instructions, important hardware files and cleaned the repo.
    [Case.SLDPRT, Case.STL, PINOUT_EliasKiln.xlsx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]
2026-04-21 feat: implement firing program library and editor
    - Add program catalog API to Network class (refreshCatalog, getProgramCount,
    getProgramEntry, handleSaveProgramBody, makeSlug, uniqueSlug)
    - New routes: GET /programs, GET /list-programs, GET /get-program?id=,
    POST /save-program; remove legacy POST /program-editor
    - Canonical JSON schema: snake_case fields, auto-computed duration, slug-based
    filenames (/prog_<slug>.json); legacy firingProgram_N.json read transparently
    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
2026-04-21 fix: adversarial review — catalog doc size, write-before-delete, date picker
    - refreshCatalog: replace StaticJsonDocument<1024> with DynamicJsonDocument(256)
    + ArduinoJson filter (name/created_date/duration only). A 20-segment program
    file exceeds 1 KB; the old code silently dropped programs from the catalog.
    Filtering also avoids parsing the segments array for metadata-only reads.
    - handleSaveProgramBody: move fileSystem.remove(existingFile) to after confirmed
    write. Previously, deleting the old file before writing the new one created a
    data-loss window if the open or serializeJson call failed. Also fixes legacy
    firingProgram_N.json files not being cleaned up when saved under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
2026-04-21 ui: fix date input alignment + add graph axis ticks
    - Add input[type=date] to CSS width/padding rule so the date picker
    matches the Name input width on wide screens
    - Rewrite updatePreview() SVG generation:
    - Y-axis: horizontal gridlines + temperature labels at nice °C
    intervals (5/10/20/25/50/100/200/… adaptive)
    - X-axis: vertical gridlines + HH:MM time labels at nice minute
    intervals (5/10/15/30/60/90/… adaptive)
    - Fallback guarantees ≥1 tick even for very short/low programs
    - viewBox grows to 300×140 when data is present (vs 120 empty)
    to give room for bottom time labels
    - Left margin 30px to fit Y-axis labels; bottom margin 22px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
2026-04-22 fix: harden firing program saves on SPIFFS
    - keep public program IDs separate from shortened SPIFFS filename slugs
    - persist IDs in saved program JSON and read them back during catalog refresh
    - cap filename slug length to stay within the ESP32 SPIFFS path limit
    - preserve stable IDs/slugs for unchanged edits while still handling rename-on-save
    - harden in-place updates with temp + backup recovery files and checked rollback
    - use hashed temp/backup filenames so recovery files do not collide or leak into the catalog
    - expand the catalog metadata filter so the persisted id field is not silently dropped
2026-04-22 improved readability of network class regarding catalogs. Changed serial prints to log_i
2026-04-22 feat: add MAX31856 support + runtime TC type selection
    - Add build-time driver selection in userSetup.h (TC_DRIVER_ADS1220 / TC_DRIVER_MAX31856)
    with #error guard ensuring exactly one is defined
    - Rename thermocoupleCS→TC_CS_PIN, thermocoupleDRDY→TC_DRDY_PIN
    - Replace TCTYPE (String) with TC_DEFAULT_TYPE (constexpr char)
    - Add shared runtime globals: g_tcType, g_tcInitialized, g_initErr, g_tcFault,
    g_tcFaultCode, g_spiMutex; rename g_fault→g_tcFault everywhere
    - Bootstrap g_tcType from Preferences in gui_start()
    - Rewrite sensor_task.cpp with dual-driver support, handleTcType abstraction,
    non-blocking readCSV (returns bool, sets g_initErr), bounds-clamped LUT lookups,
    MAX31856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
    [main.cpp, userSetup.h]
2026-04-23 feat: display TC fault errors on TFT in gui_run()
    - MAX31856: decode fault bits (CJRANGE, TCRANGE, CJ HIGH, CJ LOW,
    TC HIGH, TC LOW, OV/UV, TC OPEN) into g_initErr; skip g_pidInput
    update when faulted; clear g_initErr when no fault
    - ADS1220: set g_initErr = 'TC OPEN or over-range' in check_faults()
    when over-range; clear when fault resolves
    - gui_run(): after taking disp_mutex, check g_tcFault / g_tcInitialized
    / g_initErr inline (no recursive mutex); show red TC ERROR screen
    with fault string and 'Restart controller' footer; return early
    - Remove stale TODO comment from sensor_task.cpp
2026-04-23 refactor: rename g_initErr[64] to String g_errMsg; simplify fault display
    - Rename g_initErr (char[64]) -> g_errMsg (String) in common.h, main.cpp,
    sensor_task.cpp — removes snprintf/strlcat; String concatenation is cleaner
    - Ensure g_tcFault=true is set in setupThermocouple retry loops so the
    invariant 'non-empty g_errMsg implies g_tcFault' always holds
    - gui_run(): move TC fault check BEFORE xSemaphoreTake(disp_mutex), then
    call existing disp_error_msg() — eliminates the deadlock risk from
    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
2026-04-24 Changed readme and added 3d files of case
    [Case.SLDPRT, Case.STL, dispHeader.SLDPRT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]
2026-04-24 chore: archive add-max31856-runtime-tc-type change; sync delta specs
    - Archived change to openspec/changes/archive/2026-04-24-add-max31856-runtime-tc-type/
    - Created openspec/specs/thermocouple-driver-and-type-management/spec.md (new capability)
    - Merged TFT TC-type selection requirements into device-navigation-and-network-visibility/spec.md
2026-04-26 fix(ota): update GITHUB_CA to Sectigo Public Server Authentication chain
    GitHub rotated to a new cert chain (Sectigo Public Server Authentication
    CA DV E36 + Root E46). The old Sectigo ECC/RSA Domain Validation chain
    caused -9984 (MBEDTLS_ERR_X509_CERT_VERIFY_FAILED) on api.github.com.
    [ota.cpp]
2026-04-26 fix(ota): follow redirects on GitHub API call
    api.github.com/repos/{owner}/{repo}/... returns 301 to the canonical
    repositories/{id}/... URL. Add HTTPC_FORCE_FOLLOW_REDIRECTS so the
    ESP32 HTTPClient follows it instead of failing with code 301.
    [ota.cpp]
2026-04-26 fix(ota): update repo name to esp32-kiln-controller; fix test script SSL
    - GITHUB_REPO: ElectricKiln -> esp32-kiln-controller (repo was renamed)
    - test_ota_api.py: use certifi or unverified SSL context so the script
    works on macOS where Python ships without system CA certs
    [ota.cpp]
2026-04-26 Fix SSID polling, OTA buttons, branding, and favicon paths
    - script.js: gate SSID polling to wifi-manager page only (check for SSID1 element)
    - firmware-update.html: add button-on/button-main classes to fix grey buttons
    - index.html + network.cpp: rename 'The Kiln Controller' to 'ESP32 Kiln Controller'
    - All HTML files: update favicon path from root favicon.png to /favicon/favicon.ico
    - site.webmanifest: fix icon paths to /favicon/ subfolder + add app name
    [network.cpp]
2026-04-26 log instead of serial print on telemetry, updated favicon
2026-04-26 Add SPIFFS OTA support
    CI now builds and uploads spiffs.bin alongside firmware.bin, and appends
    both MD5 checksums to the release notes.
    Firmware: on update, flashes firmware (U_FLASH) then SPIFFS (U_SPIFFS).
    SPIFFS flash is best-effort — if it fails, the device still restarts with
    the new firmware. Backward compatible with old releases that have no
    spiffs.bin asset.
    [ota.cpp]
2026-04-26 Preserve user data during SPIFFS OTA and auto-connect after WiFi setup
    - ota.cpp: add preserveAndFlashSPIFFS() that backs up all .json files
    before flashing and restores them after remounting SPIFFS
    - ota.cpp: skip SPIFFS flash if spiffs_version.txt already matches
    the release tag, avoiding unnecessary data wipes
    - data/spiffs_version.txt: sentinel file (local_development in repo,
    release tag injected by CI before buildfs)
    - build-release.yml: write release tag to spiffs_version.txt before
    building SPIFFS image so version check works at runtime
    - network.h/cpp: add pendingCaptiveExit flag; after WiFi credentials
    are submitted, switch to WIFI_AP_STA and attempt connection; on
    succ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
    [network.cpp, ota.cpp]
2026-04-26 Fix SPIFFS user-data preservation: two-phase backup and flush before restart
    Root cause: f.size() returns 0 for files opened via openNextFile() in ESP32
    SPIFFS, causing zero-byte backups. The 'backup' log message appeared but the
    data was empty, so restored files failed JSON parsing on next boot.
    Fixes:
    - Two-phase backup: Phase 1 collects file paths via iterator (safe). Phase 2
    reopens each file by explicit path so size() is accurate and read() returns
    real content.
    - Normalize paths: prepend '/' if missing, to handle any ESP-IDF version
    difference in f.name() return format.
    - Guard against empty files (size == 0) during backup.
    - Check out.write() return value and log at log_e level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
    [ota.cpp]
